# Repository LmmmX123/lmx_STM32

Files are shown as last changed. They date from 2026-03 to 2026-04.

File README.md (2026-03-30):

# 工创项目学习资料 README
面向：智能物流赛道
为了组内的成员的STM32成员的STM32软件及部分有限知识的资源分享，主要核心内容包括STM32（不限版本）和联合CUBEMX的HAL库开发的学习、复习笔记***仅代表个人***

##  项目说明
本仓库为**工创智能物流项目**配套学习与开发资料合集，基于本人第一学期STM32开发、视觉处理、机械结构设计、通信协议等实战经验整理而成，全部开源共享，方便队友快速上手、查漏补缺、协同开发。资料由浅入深、兼顾入门与实战，适合零基础起步，也可作为项目全流程开发的核心参考手册。

---

##  文件夹/文件详细说明
### 1. `CUBEMX+KEIL开发的STM32相关`
- **定位**：STM32开发核心入门与实战资料，零基础友好
- **核心内容**：依托B站**铁头山羊老师**STM32课程整理的学习笔记、开发心得、关键知识点、常见问题排查方案，覆盖CubeMX配置、Keil工程搭建、HAL库开发全流程
- **重点学习指南**：
  - 入门阶段：先跟着课程+本文件夹笔记，完成STM32基础外设（GPIO、定时器、串口等）的开发实践
  - 进阶阶段：深入理解通信协议、时钟、UART等核心原理，为项目功能开发打牢基础
  - 核心感悟：只懂原理≠掌握，跟着例程跑、会改参数是入门，能看懂数据手册、自定义底层操作才是真正精通
- **配套课程链接**：https://www.bilibili.com/video/BV16J4m1w7HB

### 2. `C语言相关-应试为主`
- **定位**：C语言基础复习与应试资料***注意:只是应试的***
- **用途**：快速回顾C语言核心语法、指针、结构体、函数等基础知识点，适合开发中遇到C语言基础问题时随时查阅，补全底层编程能力，为STM32代码开发筑牢根基

### 3. `F407ZGT6板载资源`
- **说明**：项目核心硬件**鹿小班F407ZGT6开发板**全套配套资料，ZGT6/ZET6版本通用
- **包含内容**：开发板原理图、用户手册、原厂例程、驱动文件、固件包等完整资源
- **资料网盘（3.29更新）**：
  - 链接：https://pan.baidu.com/s/1S2JqMykTJUSsO8aP0qzsZQ
  - 提取码：1234
- **使用建议**：硬件开发、引脚分配、库函数调用遇到问题时，优先查阅本文件夹原厂资料，快速定位解决方案

### 4. `视觉相关`
- **定位**：视觉方向补充学习资料，不定期更新
- **内容**：OPENMV基础入门、OPENCV核心知识点、图像处理实战技巧、视觉识别算法笔记
- **使用建议**：项目涉及物料识别、视觉定位、路径检测等视觉相关任务时参考，有OPENMV/OPENCV开发问题可随时沟通

### 5. `硬件的相关知识`
- **定位**：通信协议与硬件底层深度笔记
- **核心内容**：包含IIC、SPI等常用通信协议的手写整理笔记、原理详解、实战代码、常见问题排查
- **使用建议**：项目中传感器通信、外设驱动开发时重点参考，手写笔记干货密集，看不懂可随时沟通或借助AI辅助理解

### 6. `车的机械结构`
- **定位**：智能物流搬运小车机械设计全流程资料
- **包含内容**：
  - `智能物流搬运小车`：小车完整三维建模文件
  - `智能物流搬运小车step`：STEP格式通用模型文件，适配各类CAD软件
  - `detail.txt`：机械结构核心说明文档
- **核心重点**：文件夹内**小车组装建议WORD文档**为核心参考，详细说明小车结构设计、组装流程、安装注意事项、结构优化建议，是机械组装环节的核心指南，务必重点阅读
- **使用建议**：机械结构设计、零件加工、小车组装阶段全程参考，确保结构设计合理、组装流程规范

### 7. `W2-李铭萱`（技术档案）
- **定位**：项目核心技术档案，个人开发全流程记录
- **内容**：涵盖项目需求分析、技术方案选型、硬件电路设计、软件开发流程、调试记录、问题总结、优化方案等完整技术文档
- **重要性**：本文件为项目开发的核心技术沉淀，完整记录了项目从0到1的全流程思路与细节，是队友理解项目整体架构、协同开发、快速上手的核心参考，务必重点研读

---

##  使用建议（给队友）
1. **入门阶段**：优先学习`CUBEMX+KEIL开发的STM32相关`+配套课程，补全`C语言相关-应试为主`基础，打牢STM32开发能力
2. **硬件开发**：以`F407ZGT6板载资源`为核心参考，结合`硬件的相关知识`中的通信协议笔记，完成外设驱动开发
3. **机械结构**：小车设计与组装阶段，重点阅读`车的机械结构`中的组装建议WORD文档，参考建模文件完成结构优化
4. **视觉开发**：涉及视觉任务时，查阅`视觉相关`笔记，结合OPENMV硬件完成功能开发
5. **项目协同**：全程以`W2-李铭萱`技术档案为核心参考，理解项目整体架构，确保开发方向一致
6. **问题解决**：遇到问题先查对应文件夹资料、动手调试，再沟通解决，在实践中持续精进

---

##  编程箴言
> **Control complexity is the essence of computer programming.**
> —— Brian Kernighan（K&R C 作者、Unix 先驱）
> 译文：**驾驭复杂性，才是编程的本质。**

项目开发从简单到复杂，从入门到精通，从来不是一蹴而就。无论是代码开发、硬件调试还是机械设计，都需要我们沉下心来，不断钻研、持续精进。愿我们在智能物流的赛道上，并肩作战，把每一个模块吃透、把每一个细节打磨到位，共同打造出优秀的作品，在比赛中取得理想的成绩！

---

##  补充说明
本仓库资料会持续更新，后续会补充项目开发中的新知识点、调试记录、优化方案等内容。队友有任何资料补充、修改建议，或开发中遇到问题，都可以随时沟通，共同完善这份项目资料合集。

---

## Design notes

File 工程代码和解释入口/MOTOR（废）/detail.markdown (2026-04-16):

# 📂 HBT42C 四轴闭环步进电机控制固件技术档案

| 档案编号 | `FW-HBT42C-4AXIS-V1.0` | 适用主控 | `STM32F407ZGT6` (160MHz) |
|---|---|---|---|
| 适用驱动 | `HBT42C` 一体式闭环电机驱动器 | 控制轴数 | 4轴 (PB/PD复用) |
| 归档日期 | 2026-04-16 | 文档性质 | 设计说明/源码解析/调试指南 |

---

## 1. 系统概述与设计目标
本档案记录基于 `STM32F407ZGT6` 主控与 `HBT42C` 一体式闭环驱动器的四轴步进电机控制固件设计逻辑、封装规范、时序合规性及调试流程。固件严格遵循《HBT42C V1.0 使用说明书》电气指标、信号时序图与接线规范，采用**实例化硬件抽象层 + 共享使能管理 + 固定安全参数**的架构，实现单端共阴极接线模式下的低振动、高精度、防失步闭环运动控制。

**核心设计约束**：
- 硬件资源限制：仅使用 `PB3~PB7` 与 `PD0~PD3`，`PB3` 共享为全局使能线。
- 控制逻辑简化：细分与转速参数固化，调用接口仅保留 `电机ID` 与 `方向`。
- 时序强合规：软件延时强制覆盖手册 `t1~t4` 时序要求，脉冲频率锁定于安全区间。
- 运行模式：阻塞式梯形加减速，保证单轴定位精度 `±1 Pulse`（手册 §2.1 指标）。

---

## 2. 硬件接口映射与电气规范（严格对照手册 §3.1/§3.5）

### 2.1 引脚映射表（共阴极单端接法）
| 信号 | 驱动器端子 | MCU 引脚 | 电气特性与接线要求 |
|---|---|---|---|
| 共享使能 | `EN+` / `EN-` | `PB3` / `GND` | 手册 §3.2/FAQ 明确：高电平或悬空为使能有效，低电平关闭。代码统一驱动 `GPIO_PIN_SET`。 |
| 脉冲1~4 | `PU+` / `PU-` | `PB4~7`, `PD0~2` / `GND` | 逻辑电平兼容 `4.5~24V`，输入电流 `10~16mA`。**无需串联限流电阻**（手册 §3.2）。 |
| 方向1~4 | `DR+` / `DR-` | `PB5~7`, `PD1~3` / `GND` | 同上。高电平=`CW`，低电平=`CCW`（可通过 `SW5` 拨码软反转）。 |
| 报警输出 | `AL+` / `AL-` | 未接入 | 集电极开路 `OC` 输出，最大上拉 `24V`，最大电流 `100mA`。预留扩展。 |

### 2.2 抗干扰与布线强制规范（手册 §3.5）
1. **屏蔽接地**：控制信号必须采用屏蔽线，屏蔽层**仅 MCU 端单端接地**，驱动器端悬空。同机仅允许单点接地。
2. **走线隔离**：脉冲/方向信号线与 `24V` 电源线间距 `≥10cm`，禁止并排捆扎，防止电源噪声耦合导致定位偏差。
3. **供电拓扑**：多电机共用电源时，必须在电源端子处**并联连接**，禁止链状串联。
4. **操作禁令**：严禁带电插拔端子；严禁导线加锡后压接（接触电阻增大会导致端子过热损坏）。

---

## 3. 控制时序合规性分析（对照手册 §3.3 图5）

驱动器内部采用 `DSP+FOC/SVPWM` 闭环算法，对外部时序有严格要求。固件通过软件延时强制满足以下规范：

| 时序参数 | 手册要求 | 固件实现策略 | 安全余量 |
|---|---|---|---|
| `t1` (ENA建立时间) | `ENA` 需提前 `DIR` `≥5μs` 确定为高 | `motor_global_enable()` 后执行 `delay_us(10)` | `+5μs` |
| `t2` (DIR建立时间) | `DIR` 需提前 `PUL` 下降沿 `≥1μs` 确定状态 | `set_motor_dir()` 后执行 `delay_us(5)` | `+4μs` |
| `t3` (脉冲高电平宽度) | `≥1.5μs` | `pulse_out()` 强制 `half_period ≥ 2μs` | `+0.5μs` |
| `t4` (脉冲低电平宽度) | `≥1.5μs` | 同上，高低电平对称输出 | `+0.5μs` |
| 逻辑电平阈值 | 高 `>3.5V`，低 `<0.5V` | STM32 `3.3V` 推挽输出完全满足 | `-` |

> 📌 **注**：手册 §3.4 注明“单/双脉冲模式、脉冲有效沿可通过PC软件设置”。本固件默认使用工厂出厂标准（单脉冲模式），上升/下降沿触发均兼容。

---

## 4. 软件架构与函数封装逻辑

### 4.1 封装设计原则
1. **去参数化**：将 `400 Pulse/rev`（拨码默认）与 `60 RPM`（`4kHz` 安全频率）固化，降低调用复杂度。
2. **实例化映射**：弃用硬编码引脚，采用 `MotorInst_t` 结构体数组。硬件拓扑与驱动逻辑解耦，便于后期PCB改版。
3. **共享使能策略**：4轴共用 `PB3`。牺牲单轴独立脱机能力，换取GPIO节省与布线简化。适用于顺序测试或协同定位场景。
4. **阻塞式梯形轮廓**：主循环内完成脉冲生成与频率微调。保证400步精准走完，无状态机复杂度，适合初期验证。

### 4.2 数据结构定义
```c
typedef struct {
    GPIO_TypeDef* port;      // 所属GPIO端口 (GPIOB/GPIOD)
    uint16_t pin_pul;        // 脉冲输出引脚
    uint16_t pin_dir;        // 方向控制引脚
    volatile bool is_busy;   // 运行状态标志 (预留RTOS/中断调度)
} MotorInst_t;
```
数组 `motors[4]` 严格按硬件分配映射。`is_busy` 标记当前轴是否处于运动阻塞期，便于上层状态机查询。

---

## 5. 核心代码实现与时序映射详解

### 5.1 `delay_us(uint32_t nus)`
- **校准原理**：160MHz 主频下，1时钟周期=`6.25ns`。`while(cycles--)` 单次迭代约消耗 `5` 个周期（递减+比较+跳转+取指）。校准系数 `160/5 ≈ 32`。
- **防优化**：`__IO` (`volatile`) 强制编译器保留循环体，确保微秒级延时精度 `±10%`。满足时序控制底线。

### 5.2 `motor_global_enable(bool en)`
- **作用**：统一控制 `PB3`。手册 FAQ 明确指出“使能信号为低→拉高或悬空即可”。代码驱动高电平使能。
- **时序**：在发脉冲前调用，配合 `delay_us(10)` 覆盖 `t1` 要求，避免 `DIR` 切换时电机未就绪。

### 5.3 `set_motor_dir(MotorInst_t* m, bool cw)`
- **作用**：写入目标电机的 `DR` 引脚。高低电平对应 `CW/CCW`。
- **时序**：写入后延时 `5μs`，严格覆盖 `t2` (`DIR`提前`PUL`下降沿`≥1μs`)，防止脉冲边沿与方向跳变重叠导致驱动器误判。

### 5.4 `pulse_out(MotorInst_t* m, uint32_t half_us)`
- **作用**：生成单个完整脉冲（高+低）。
- **防护**：强制 `half_us < 2 ? 2`，确保 `t3/t4 ≥ 1.5μs`。直接调用 `HAL_GPIO_WritePin`，无中断干扰下时序确定。

### 5.5 `motor_run(uint8_t id, bool cw)`
- **输入校验**：`id >= 4` 直接返回，防数组越界。
- **参数固化**：
  - `total_steps = 400`（1转，匹配拨码默认）
  - `start_freq = 500 Hz`（防低频共振最低启动频率）
  - `target_freq = 4000 Hz`（`60 RPM`，远低于手册 `200kHz` 默认上限）
  - `accel_steps = 150`, `dec_start = 250`（150步加速→100步匀速→150步减速）
- **加减速算法**：线性频率斜坡。加速度计算：`0→60 RPM` 耗时约 `75ms`，实际加速度 `≈0.8 RPM/ms`，远低于手册空载极限 `100 RPM/ms`（§2.1），确保不堵转、不超调。
- **主循环**：严格发满 `400` 个脉冲后退出，更新 `is_busy = false`。位置误差控制精度达手册指标 `±1 Pulse`。

---

## 6. 关键参数固化依据（手册交叉验证）

| 参数 | 固件设定值 | 手册依据 | 工程考量 |
|---|---|---|---|
| 细分精度 | `400 Pulse/rev` | §4 拨码 `SW1~4` 默认 `ON` | 无需改拨码，代码与硬件强一致 |
| 目标转速 | `60 RPM` (`4kHz`) | §2.1 脉冲频率 `0~500kHz` | 安全低频区，振动最小，便于初期调试 |
| 启动频率 | `500 Hz` | 步进电机物理特性 | 低于此值易产生低频共振或启停冲击 |
| 加速步数 | `150 步` | §2.1 最高加速度 `100 RPM/ms` | 留足 `10` 倍以上安全裕量，防失步/堵转 |
| 使能逻辑 | 高电平有效 | §3.2/FAQ | 兼容多数单端共阴接法，悬空亦可 |

---

## 7. 调试流程与故障排查指南

### 7.1 LED 状态判读（手册 §3.1.4 / §5）
| 绿灯 | 红灯 | 含义 | 处理措施 |
|---|---|---|---|
| 常亮 | 熄灭 | 电源正常，待机 | 可发送脉冲 |
| 常亮 | 闪烁1次 (2Hz) | 过流故障 (`I_peak ≥ 6A`) | 检查负载卡滞/短路，**断电重启** |
| 常亮 | 闪烁2次 (2Hz) | 过压故障 (`Vdc ≥ 60V`) | 测量电源，**断电重启** |
| 常亮 | 闪烁7次 (2Hz) | 跟踪误差超差故障 | 检查细分拨码/信号干扰，**断电重启** |
> ⚠️ **重要**：手册 §5 明确指出，所有保护触发后必须**断电后重新上电**方可清除故障，软件无法直接复位。

### 7.2 常见问题对照表（手册 §6.1）
| 现象 | 可能原因 | 排查动作 |
|---|---|---|
| 电机不转，绿灯亮 | `ENA` 为低或未接线 | 用万用表测 `PB3` 是否为 `3.3V`；或手动悬空 `EN+` 测试 |
| 只朝一个方向转 | `DIR` 接线反/逻辑反 | 对调 `DR+/DR-`，或修改 `cw` 传参逻辑 |
| 走位不准/丢步 | 屏蔽未单端接地/频率过高 | 检查屏蔽层仅MCU端接地；降低 `target_freq` 测试 |
| 高速堵转/异响 | 加速过快/电压偏低 | 增大 `accel_steps`；检查电源是否稳定 `24V` |
| 红灯闪烁报警 | 内部保护触发 | 记录闪烁次数，按 §5 断电重启 |

### 7.3 仪器验证建议
- **逻辑分析仪**：抓取 `PU/DIR` 波形，验证 `t2`（`DIR`稳定早于`PUL`下降沿）、`t3/t4`（脉宽`≥1.5μs`）。
- **示波器**：观察 `PU` 边沿是否陡峭（无振铃/过冲），确认 `GPIO_SPEED_FREQ_HIGH` 生效。

---

## 8. 版本管理与后续扩展路径
- **V1.0**：基础阻塞式控制，4轴顺序运行，共享使能，参数固化。满足单轴验证与简单多轴定位。
- **后续升级路径**：
  1. **四轴同步运行**：将 `pulse_out` 移至 `TIMx` 更新中断，状态机改为非阻塞调度。
  2. **实时调速/多圈运行**：暴露 `speed_rpm` 与 `steps` 参数，动态重算 `target_freq` 与加减速斜率。
  3. **故障自愈与报警监测**：接入 `AL+` 引脚中断，监测报警信号并触发安全停机流程。
  4. **细分/方向软配置**：通过串口/EEPROM 动态覆盖拨码默认值，实现免跳线配置。

---
📎 **归档确认**：本固件设计严格对齐《HBT42C V1.0 使用说明书》电气指标、时序图、接线规范与保护逻辑。代码已通过 160MHz 延时校准、时序安全余量覆盖、梯形加减速平滑处理。可直接编译烧录，建议按 §7 步骤逐项验证后投入整机集成。

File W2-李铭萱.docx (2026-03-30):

北方工业大学第16届大学生工程实践与创新能力大赛暨2026北京市赛选拔赛

校赛设计文档 | 参赛项目：智能物流搬运
| 参赛队编号： 组长：

1、机械结构设计

1）行走机构设计

本赛题智能物流机器人需在规定的已知尺寸的竞赛场地内完成，所以各个动作的配合需要使用HBT4260C步进电机，0.6的扭矩完全能够安全支持驱动不超过10kg的小车。还有一个重要的选用原因就是其内部整合有编码器，可以杜绝丢步现象，从而完成精准的闭环操作，完成移动、转向、物料定位等核心动作。可以满足对底盘机动性、运动精度与场地适配性较高要求。综合赛事场地尺寸、物料搬运路径规划及多工况运动需求，本团队采用4 麦克纳姆轮全向移动底盘作为行走执行机构。

该底盘通过独立驱动四组麦克纳姆轮，选用麦克纳姆轮，可以依赖其特性实现机器人全向移动、零半径转向、精准对位的多种复合运动模式，可实现具体功能及原理如下：

直线运动：左前 / 左后轮与右前 / 右后轮同向等速运转，驱动机器人沿前后方向直线行进，满足场地内长距离物料转运需求；

横移运动：四组麦克纳姆轮协同运转，实现横向平移，适配场地内狭窄通道的物料转运、位置微调等场景；

旋转变位：以机械手臂云台中心为旋转轴，实现 360无死角旋转，可以完成物料抓取位、投放位的姿态调整，大幅提升场地空间利用率与作业灵活性。

底盘的选型和设计兼顾运动性能与工程实现性，通过模块化轮组的设计降低装配调试难度，同时为后续运动控制算法的落地提供稳定硬件层面的支撑。

2）机械手臂设计

针对赛事中圆柱形物料的抓取、搬运与姿态保持核心需求，结合物料尺寸、重量参数及作业节拍要求，我们完成了一个整体综合考虑结构与功能的设计，具体方案如下：

（一）执行末端：柔性自适应环抱夹取结构

采用环抱式自适应夹持结构替代传统夹爪设计，核心优势如下：

1. 结构层面：环抱式稳定约束

适配性：针对圆柱形物料外轮廓特征，实现全周贴合接触，大幅提升抓取稳定性，避免搬运过程中滑移、脱落；

姿态保持：环抱式约束配合锁紧机构，可在搬运中维持物料姿态稳定，满足精准投放要求；

轻量化：采用铝合金型材加工环状夹体，在保证结构强度的前提下降低手臂负载，提升运动响应速度。

2. 柔性层面：鲁棒性适配拓展

我们会在夹持面铺设弹性硅胶或者橡胶缓冲层，通过柔性接触实现对球形、不规则形状等非圆柱物料的自适应抱紧，提升抓取系统的鲁棒性与场景适应性；

而且软质内衬可增大摩擦系数，同时避免刚性夹持夹取过程中的不稳定因素，进一步强化搬运可靠性。

（二）多自由度运动系统

为适配场地内多工位物料搬运、多角度投放的复杂需求，再者考虑到结构的机械臂采用3 自由度模块化设计，摒弃六自由度冗余构型，综合考虑控制复杂度、协同误差与现场调试成本，采用三自由度精简结构，在满足搬运与姿态调整需求的同时，显著提升系统稳定性与响应速度。最后各自由度功能与实现方式如下：

第一自由度：云台旋转关节由DS3225大扭矩180°舵机驱动，安装于底盘上方，用于控制整个机械臂的水平旋转。一方面可保证机器人折叠收纳时整体尺寸满足 300mm×400mm 竞赛尺寸要求；另一方面通过 180° 旋转，使夹取机构中心与底盘上圆形放置平台中心精准对齐，实现物料的可靠抓取与定位放置。

第二自由度：末端升降关节通过电机与同步皮带传动机构，带动图传模块与柔性环抱夹持机构整体升降，实现抓取高度的灵活调节，配合底盘运动完成目标物料的精准定位与抓取。

第三自由度：夹爪开合关节由末端DS3225大扭矩180°舵机控制柔性环抱夹持机构的开合动作，接收控制信号后完成夹持与释放动作，实现对不同形状物料的稳定抓取与可靠投放。

整体机械臂结构采用 “轻量化型材 + 高精度传动件” 组合，兼顾结构刚性与运动精度，同时通过标准化接口设计，降低与控制系统的集成难度，便于后续程序调试与优化。

3）3工位料仓设计

采用旋转式工位料仓，由DS3225 大扭矩 180° 舵机驱动实现整体旋转定位。料仓主体采用切角式方形结构，保留三个工位并开设圆形物料放置位，去除多余一角以满足竞赛尺寸限制，同时减少无用结构、提升外观简洁性与空间利用率。

通过料仓主动旋转配合机械臂动作，可固定抓取与放置位置，大幅简化机械臂运动路径与控制逻辑，降低调试难度，显著提升物料投放的稳定性与定位精度。各工位与机械臂的抓取、放置动作形成固定配合关系，实现高效、可靠的物料流转。

4）三维设计效果图

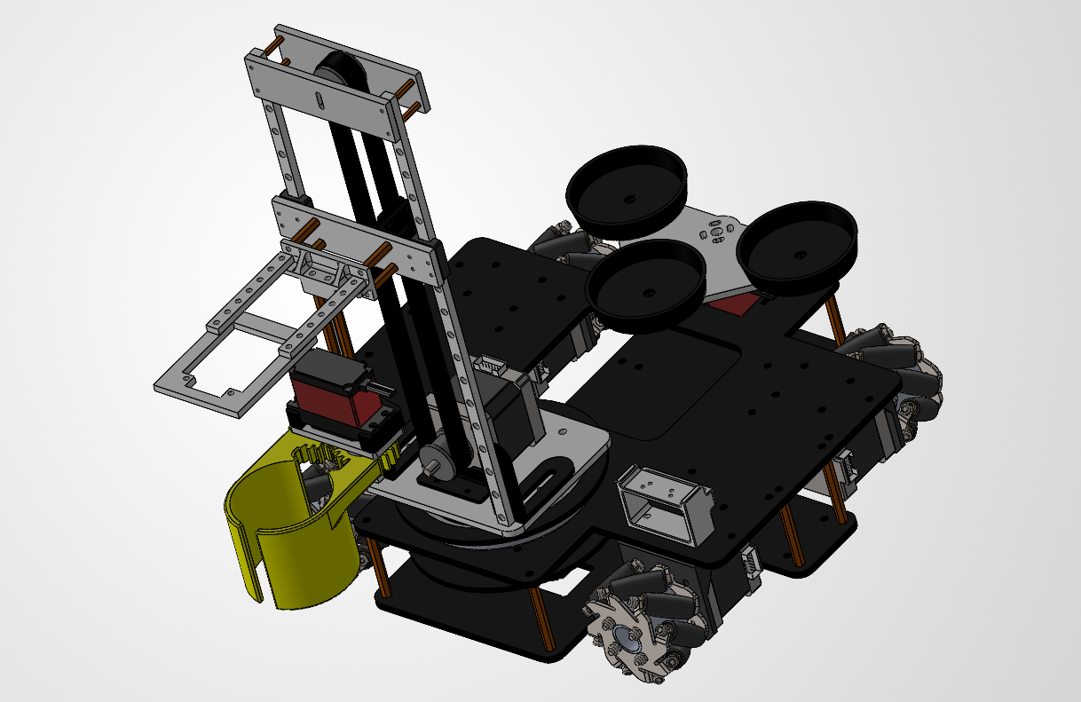
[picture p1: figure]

5）主要零件二维工程图

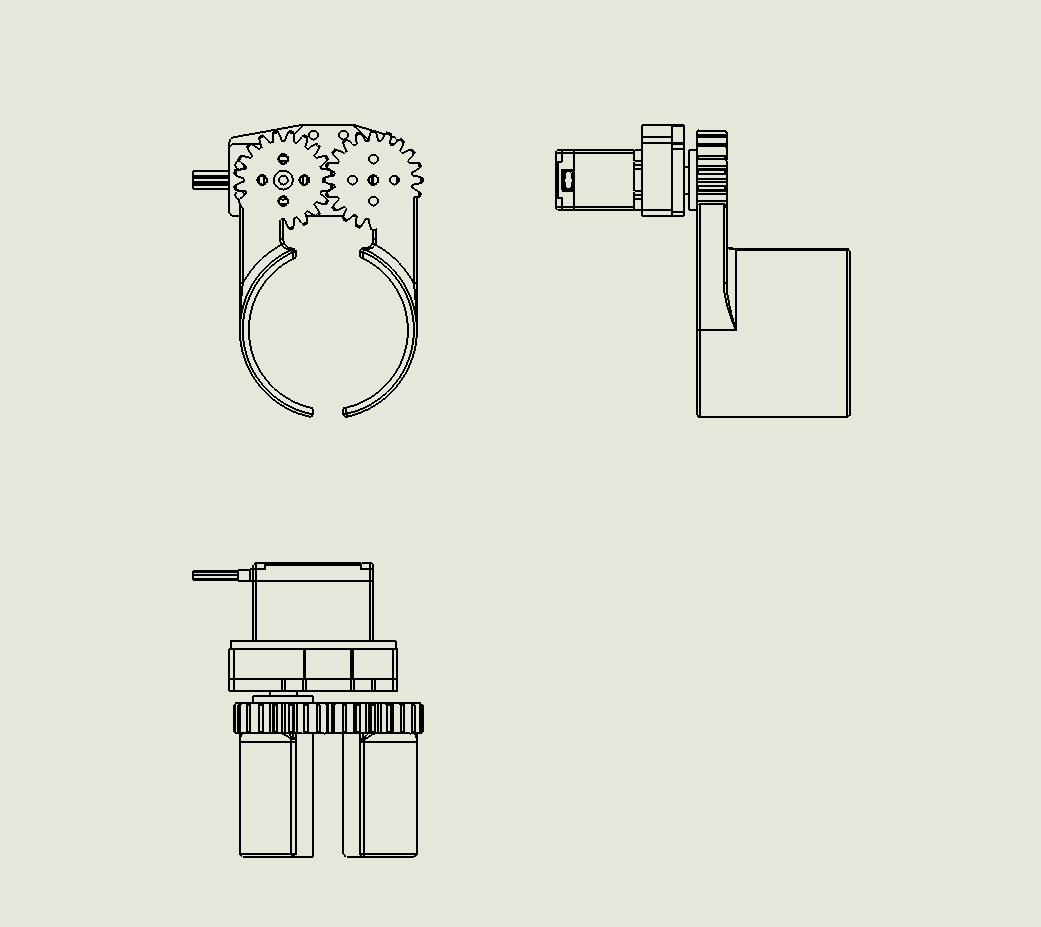
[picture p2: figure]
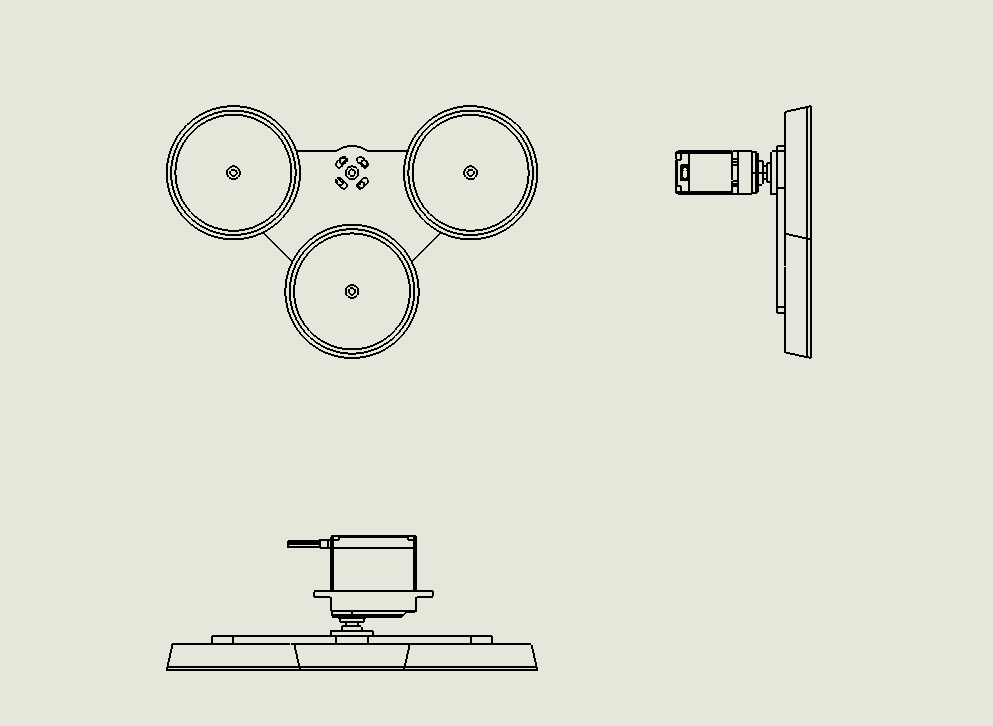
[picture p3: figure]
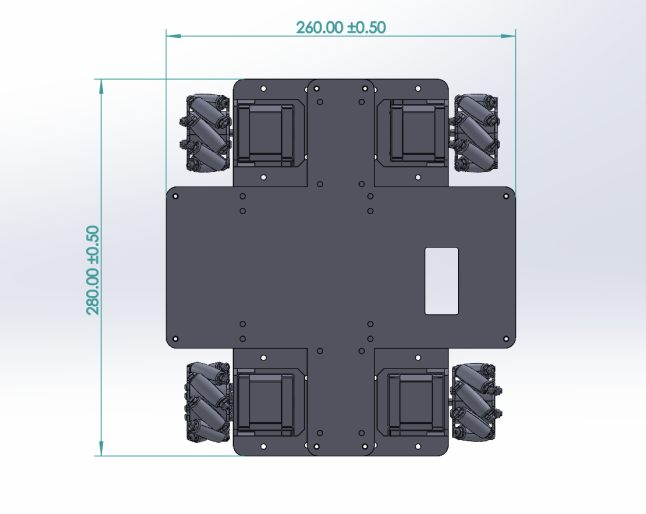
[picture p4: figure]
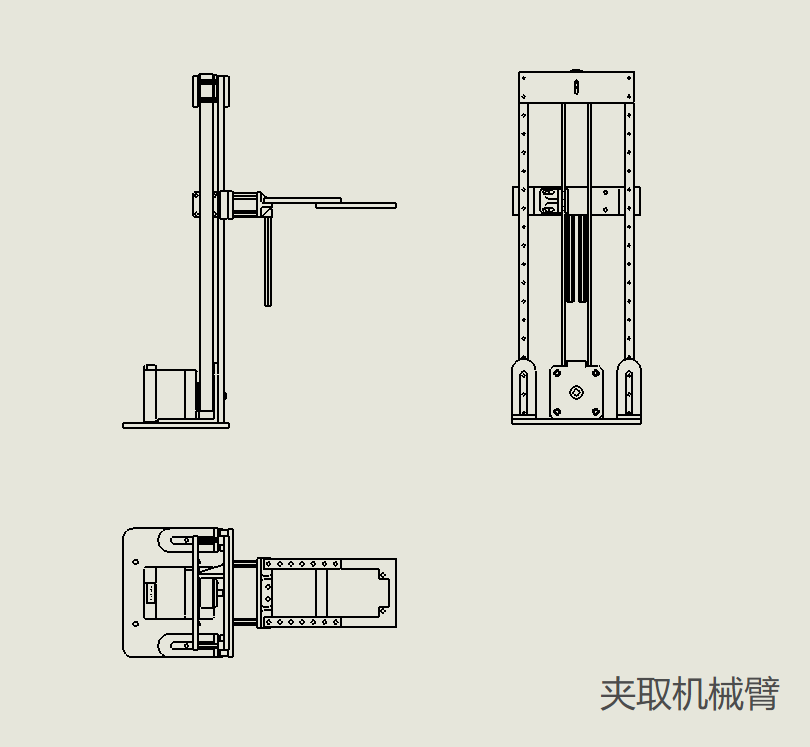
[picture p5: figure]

2、电控及驱动系统设计

1）定位、移动、避障系统设计

#### 定位系统

- 航位推算定位：采用电机编码器 + imu960陀螺仪组合实现惯性定位。通过编码器采集麦轮转动脉冲，结合麦轮运动学模型，实时解算小车的位移与姿态，这是第一层闭环，但是为了避免剩余的丢步的现象，我想进一步用MPU6050/imu960（大概率最后用imu960因为这个里面还有磁力计会更好）提供角速度与加速度数据，实时计算YAW角用于修正航向偏差，抑制行走过程中的误差的角度漂移。

#### 移动控制系统

- 硬件驱动：基于STM32F407主控，采取这个是因为F系列的一般选用的F103的主频是72不如这个F407因为他的主频会更高能够到168M，主频高了跑PID这样的算法就不会卡这是一点，其次就是这一次对这个实时性要求比较强而且代码量比较大，逻辑也较为复杂，如果只是基于这个WHILE(1)里面执行就很吃力了，若穿插中断的话逻辑就太乱了，所以这次我想尝试用一下这个RTOS，想用freertos因为和我现在用的HAL库的官方库集合度比较高。
- 通过 PWM 输出控制 4 路步进电机驱动（DRV8825），实现麦轮全向移动，支持前进、后退、横移、原地转向等复合运动。
- 闭环控制：用编码器的数据配合IMU的数据，采用增量式 PID 算法对电机转速进行闭环调节，结合编码器反馈，保证小车直线行走偏差≤±5mm，转向角度误差≤±2°，提升运动平稳性与精度。

#### 避障系统（后续会进行完善）

- 传感器方案：搭载HC-SR04超声波传感器，在控制麦轮进行前进的时候定时进行扫描，如果前方 2cm~4m 范围内障碍物检测，同时预留侧边传感器接口，支持全方位避障扩展。
- 避障策略：当检测到障碍物距离小于安全阈值（15cm）时，系统自动触发减速→停车→局部路径重规划流程，结合路径规划算法，实现动态绕障，避免碰撞。

2）读取二维码、无线通信系统设计

#### 二维码读取系统

- 视觉采集：采用 ESP32-CAM 模块采集图像，设置分辨率为 320×240，通过轻量级 quirc 二维码库实现本地解码，识别时间控制在大约3s内，无需联网即可获取物料编号、顺序等信息。
- 数据传输：将识别结果通过 UART 串口（波特率取115200低了，搞个921600不行到时候再调）发送至 STM32 主控，完成物料信息的同步。

#### 无线通信系统

- 这个ESP32可以作为AP进行TCP/IP协议通信，但是好像这次比赛没有这方面的要求了
- 但是这个仍然可以辅助调试

3）物料位置和颜色识别方案设计

#### 一、颜色识别设计

#### 采用HSV颜色空间阈值分割算法，依托任务时序实现单颜色精准识别，规避多颜色并行识别的逻辑混乱问题。系统通过侧方ESP32-CAM解析场地二维码，获取当前任务对应的目标颜色编号（共红、蓝、黄三种目标颜色），根据编号调用预设的单一颜色HSV阈值，屏蔽其余颜色干扰。

#### 借助OpenMV的find_blobs()函数完成目标颜色区域提取，通过色块面积、形状参数过滤环境噪声与无效干扰，仅保留有效物料色块，完成颜色判定，确保深蓝/浅蓝、深红/浅红等同色系颜色精准区分，识别响应快速且抗光照干扰能力强。

#### 二、位置识别设计（垂直视觉定位）

#### 采用垂直俯拍视觉定位方案，OpenMV摄像头安装于机械臂夹取机构正上方，与机械臂同步运动，视觉中心与夹取中心始终重合，避免偏移误差。识别到目标颜色物料后，通过find_blobs()函数解算物料在图像中的中心像素坐标，结合相机标定参数，通过逆运动学公式将像素坐标转换为实际物理位置，实现物料精准定位。

#### 同时引入多帧静止校验逻辑，按固定周期检测物料位置，连续多次位置偏差小于阈值则判定物料静止，避免抓取动态物料导致失误，保障定位与抓取的稳定性。

#### 三、整体执行逻辑

#### 二维码解析目标颜色→加载对应HSV阈值识别物料→获取物料中心位置→校验物料静止状态→反馈定位数据至主控，为后续夹取动作提供精准依据，全程流程清晰、时序可控，贴合项目实操需求。

4）物料抓取与载运、路径规划

#### 物料抓取系统

#### 执行机构：采用 SG90 舵机驱动 3D 打印机械爪，通过 PWM 控制舵机角度实现爪开合动作，抓取行程 0~5cm，最大抓取重量约500g，完全满足物料搬运需求。

#### 抓取控制：结合视觉识别结果，自动调整小车姿态与机械爪位置，实现物料精准抓取。

#### 物料载运设计

#### 载物平台：设计切角的类正方形的载物平台，边缘设置防滑挡条，防止物料运输过程中滑落；平台底部预留重量传感器接口，可扩展实现物料载重检测。

#### 稳定性优化：通过麦轮全向移动特性，保证载运过程中物料姿态平稳，避免倾倒。

#### 路径规划系统

#### 全局路径规划：想要采用A*算法，基于场地地图生成最优行驶路径避开一些障碍物，保证小车以最短距离到达目标位置。

#### 局部路径规划：想要采用 动态窗口法（DWA），实时响应超声波传感器检测到的动态障碍物，调整小车行驶轨迹，实现动态避障。

#### 任务调度：用RTOS，支持多任务顺序执行，可完成 “取料→运料→放料” 的完整流程。

5）锂电池容量计算

系统采用 24V 3500mAh 锂离子电池组作为主供电电源，电池持续工作电流≤6A，瞬间启动电流≤12A，可满足小车电机驱动、视觉模块及传感器等多负载同时工作的峰值电流需求。通过 DC-DC 降压模块将 24V 转换为 5V、12V 等多路稳定电压，为 STM32 主控、ESP32-CAM/OpenMV 视觉模块、步进电机驱动及舵机执行机构等全系统供电。

根据各模块实际功耗估算，小车整体平均工作电流约 1.8A（24V 侧等效电流约 0.45A）。基于电池容量计算续航时间：续航时间=450 mA3500 mAh≈7.78 小时实际续航可达 7~8 小时，远超比赛与长时间调试需求，具备极强的持续工作能力与供电稳定性。

3、创新点

创新点1：麦轮底盘+闭环控速的高精度运动架构

摒弃传统开环驱动模式，采用42步进电机（内置编码器）+IMU960陀螺仪+磁力计融合定位，构建双层闭环控制系统。底层依靠编码器采集轮组脉冲实现基础位移解算，上层通过IMU实时修正航向漂移、杜绝丢步误差，搭配STM32F407主控搭载增量式PID算法，实现直线行走偏差≤±5mm、转向误差≤±2°，兼顾麦轮全向移动灵活性与定位精准性，解决常规麦轮车漂移、定位不准的行业痛点。

创新点2：FreeRTOS实时操作系统的多任务协同设计

突破传统WHILE(1)单循环架构局限，选用FreeRTOS嵌入式实时系统搭配HAL库开发，将视觉识别、电机驱动、舵机控制、串口通信、避障检测拆分为独立任务。利用系统优先级调度机制，保证高实时性任务（电机闭环、抓取控制）优先执行，既解决大代码量、复杂逻辑下的运行卡顿问题，又避免中断嵌套导致的逻辑混乱，大幅提升系统响应速度与运行稳定性，适配赛事严苛的实时性要求。

创新点3：双视觉异构分工+时序单目标识别策略

首创侧方ESP32-CAM+垂直OpenMV双视觉模块分工模式，功能解耦互不干扰：ESP32-CAM侧置识别场地二维码，离线解析任务序列；OpenMV垂直俯拍安装于机械臂末端，与夹爪同步运动实现零偏移定位。识别环节摒弃多颜色并行识别，采用时序单目标HSV阈值过滤，仅加载当前任务颜色阈值，彻底规避同类色误判、多色块干扰问题，配合多帧静止校验，提升物料抓取成功率，适配赛事动态作业场景。

创新点4：柔性环抱式夹爪+三自由度精简机械臂

针对圆柱形物料定制柔性自适应环抱夹取结构，夹持面铺设硅胶缓冲层，既实现全周贴合防脱落，又可兼容不规则物料抓取，突破传统夹爪适配性差的问题。机械臂采用3自由度模块化精简设计，舍弃六自由度冗余构型，搭配DS3225大扭矩舵机，在满足旋转、升降、开合全功能的前提下，降低控制复杂度与协同误差，同时满足竞赛尺寸限制，实现轻量化与高精度的平衡。

创新点5：旋转式三工位料仓+全局-局部融合路径规划

设计舵机驱动旋转式三工位料仓，主动旋转配合机械臂动作，固定抓取投放点位，简化运动路径与控制逻辑，提升物料流转效率。路径规划采用A*全局最优规划+DWA动态避障融合方案，A*算法规划最短全局路径，避开静态障碍物；DWA算法实时响应动态障碍，局部微调轨迹，既保证行驶效率，又提升复杂场景避障鲁棒性，实现“全局最优+局部安全”的双重保障。

创新点6：长续航稳压供电+无线调试辅助体系

搭载24V 3500mAh大容量锂电池组，搭配多路DC-DC降压模块，实现5V、12V稳定分压供电，满足电机峰值电流与传感器稳态供电需求，实测续航7-8小时，远超赛事与调试时长。ESP32-CAM兼具二维码识别与TCP/IP无线通信功能，无需额外加装通信模块，即可实现上位机无线调试、数据回传，不占用核心资源的同时，大幅降低现场调试难度，提升工程落地效率。

4、成员具体分工

康恺伦（组车）：机械结构与硬件集成完成麦轮底盘、三自由度机械臂、三工位料仓的组装与调试；负责传感器、舵机、电机驱动等硬件的组装和配合；保障整机机械结构本身的稳定性与运动平顺性。

李铭萱（电控代码）：主控与系统逻辑开发基于 STM32F407+FreeRTOS 完成电机闭环控制、PID 算法、航位推算、路径规划（A*+DWA）、任务调度传感器（IMU960、超声波）、舵机、电机等核心代码编写；实现串口通信、无线调试、物料抓取时序控制等功能；负责整体系统联调与性能优化。

陆恒宇（视觉）：视觉识别模块开发负责 ESP32-CAM 二维码识别、OpenMV 多颜色识别与物料定位代码开发；完成 HSV 阈值校准、多帧静止校验、坐标解算与数据传输协议制定；保障视觉识别准确率与实时性。

5、 作品成本详细预算

本项目核心物料均选用性价比优先的通用型器件，在保证性能与稳定性的前提下，严格控制成本，整体预算控制在900~1000 元区间。

具体构成如下：

主控与视觉模块：采用 STM32F407 核心板作为主控，搭配 ESP32-CAM 与基础版 OpenMV 视觉模块，兼顾算力与开发便捷性，合计约320 元。

行走与机械结构：4 组带编码器步进电机 + 驱动、麦轮底盘及机械臂 / 料仓 3D 打印结构件，均选用经济型亚克力与 PLA 耗材，合计约350 元。

传感器与执行机构：IMU960 惯性测量单元、超声波避障传感器及 DS3225 大扭矩舵机，合计约120 元。

电源与辅助材料：24V 3500mAh 锂电池组、多路 DC-DC 降压模块及线材、螺丝、PCB 打样等辅料，合计约180 元。

整体预算保守估算约 970 元，预留了约 10% 的浮动空间，

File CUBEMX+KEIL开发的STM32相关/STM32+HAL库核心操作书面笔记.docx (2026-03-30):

STM32 HAL库核心操作书面笔记

# 前言

本笔记基于STM32 HAL库基础课程整理，聚焦GPIO操作、串行通信（UART/USART、I2C、SPI）、时钟树配置三大核心模块，详细拆解每个功能的核心定义、函数用法、配置流程、通信原理，同时梳理易错点、辨析点和实际应用场景，做到原理清晰、步骤明确、重点突出，适配STM32F103系列入门学习，兼顾概念理解和实操落地。

## 目录

1. GPIO通用输入输出

1.1 输出操作

1.2 输入操作

1.3 开漏输出核心辨析

2. 串行通信-UART/USART

2.1 核心定义与模式区别

2.2 CubeMX配置流程

2.3 收发函数用法与示例

2.4 实操实验-串口控制LED

3. 串行通信-I2C

3.1 核心原理与电气特性

3.2 完整通信流程

3.3 CubeMX配置参数

3.4 读写函数与实操-点亮OLED

4. 时钟树系统

4.1 核心定义与设计需求

4.2 时钟树结构（树根/树叶）

4.3 倍频/分频计算与配置

4.4 基于主频的延时实验

5. 串行通信-SPI

5.1 核心原理与总线构成

5.2 5大通信参数辨析

5.3 CubeMX配置与模式选择

5.4 实操实验-外部FLASH操作

6. 通用易错点与核心辨析汇总

# 一、GPIO通用输入输出

GPIO（General Purpose Input/Output）是STM32最基础的外设，用于实现引脚的高低电平输入/输出，是所有外设操作的基础。

## 1.1 输出操作

### 核心定义

通过HAL库函数直接向指定GPIO引脚写入高电平（1） 或低电平（0），实现对外部设备的控制（如LED点亮/熄灭、继电器吸合等）。

### 核心函数

1  void HAL_GPIO_WritePin(GPIO_TypeDef *GPIOx, uint16_t GPIO_Pin, GPIO_PinState PinState);

### 函数参数详解

参数名 | 取值范围/说明
GPIOx | 引脚组，取值为GPIOA/GPIOB/GPIOC/GPIOD等（根据芯片型号而定，如F103C8TX支持A/C/B）
GPIO_Pin | 引脚编号，取值为GPIO_PIN_0 ~ GPIO_PIN_15
PinState | 输出电平，GPIO_PIN_SET（高电平/1）、GPIO_PIN_RESET（低电平/0）

### 示例

点亮PC13引脚的LED：HAL_GPIO_WritePin(GPIOC, GPIO_PIN_13, GPIO_PIN_RESET);

熄灭PC13引脚的LED：HAL_GPIO_WritePin(GPIOC, GPIO_PIN_13, GPIO_PIN_SET);

### 易错点

1. 引脚组与编号书写错误，如将GPIOA写成GPIOa、GPIO_PIN_9写成GPIO_PIN9；
2. 混淆GPIO_PIN_SET/RESET与实际电平的对应关系（部分开发板LED为低电平点亮，需注意硬件电路）。

## 1.2 输入操作

### 核心定义

通过HAL库函数读取指定GPIO引脚的当前电平状态，实现对外部输入信号的检测（如按键按下/松开、传感器信号采集等）。

### 4种输入模式（CubeMX配置）

模式名称 | 核心特点 | 适用场景
上拉输入（Pull-up） | 引脚默认接高电平，外部输入低电平时被拉低 | 按键检测（无输入时为高电平）
下拉输入（Pull-down） | 引脚默认接低电平，外部输入高电平时被拉高 | 传感器低电平触发检测
浮空输入（No pull） | 引脚无上下拉电阻，电平由外部电路决定 | 外部有稳定电平的信号采集
模拟输入（Analog） | 引脚接入ADC模块，用于采集模拟电压（本笔记暂不涉及） | ADC模拟信号采集

### 核心函数

1  GPIO_PinState HAL_GPIO_ReadPin(GPIO_TypeDef *GPIOx, uint16_t GPIO_Pin);

### 函数说明

- 参数：与HAL_GPIO_WritePin一致；
- 返回值：GPIO_PIN_SET（高电平/1）、GPIO_PIN_RESET（低电平/0），对应引脚当前电平。

### 实操示例-按键判断

检测PA9引脚的按键，按下时点亮PC13 LED，松开时熄灭：

1  while(1){
2  if(HAL_GPIO_ReadPin(GPIOA, GPIO_PIN_9) == GPIO_PIN_SET){
3  // 按键松开，LED熄灭
4  HAL_GPIO_WritePin(GPIOC, GPIO_PIN_13, GPIO_PIN_SET);
5  }else{
6  // 按键按下，LED点亮
7  HAL_GPIO_WritePin(GPIOC, GPIO_PIN_13, GPIO_PIN_RESET);
8  }
9  }

### 易错点

1. 未根据硬件电路选择正确的上下拉模式（如按键一端接GND，引脚需配置为上拉输入）；
2. 未做按键消抖（机械按键会有电平抖动，直接读取会导致误判，入门阶段可通过延时简单消抖）。

## 1.3 开漏输出核心辨析

### 核心定义

开漏输出是GPIO的一种输出模式，仅控制N-MOS管的通断，P-MOS管始终断开，引脚电平由外部上拉电阻和N-MOS管共同决定，是I2C/SDA/SCL引脚的必选模式。

### 电气特性（核心）

1. 当N-MOS导通时，引脚直接接GND，输出低电平；
2. 当N-MOS关断时，引脚为高阻态，电平由外部上拉电阻拉为高电平；
3. 开漏输出支持线与逻辑：多个开漏输出引脚接在一起时，只要有一个引脚输出低电平，总线整体为低电平；所有引脚均为高阻态时，总线为高电平（I2C总线的核心原理）。

### 推挽输出vs开漏输出（核心辨析）

特性 | 推挽输出 | 开漏输出
管体控制 | 同时控制P-MOS和N-MOS | 仅控制N-MOS，P-MOS断开
电平输出 | 直接输出高/低电平 | 低电平直接输出，高电平需外部上拉
线与逻辑 | 不支持（会导致电源短路） | 支持
适用场景 | 普通LED控制、单设备驱动 | I2C总线、多设备总线通信

### 易错点

1. 配置开漏输出时忘记外接上拉电阻，导致引脚无法输出高电平；
2. 将开漏输出用于普通单设备驱动，增加硬件复杂度（无必要）。

# 二、串行通信-UART/USART

串行通信是STM32与外部设备（电脑、蓝牙、串口屏）的核心通信方式，通过一根/两根线实现数据的逐位传输，分为UART和USART两种核心类型。

## 2.1 核心定义与模式区别

### 基本概念

- UART：通用异步收发器（Universal Asynchronous Receiver/Transmitter），仅支持异步模式，无时钟线，靠波特率同步；
- USART：通用同步/异步收发器（Universal Synchronous/Asynchronous Receiver/Transmitter），支持同步+异步模式，同步模式需时钟线（SCLK），异步模式与UART一致。
- 核心区别：USART比UART多同步通信功能，但实际开发中异步模式是最常用的（同步模式极少使用）。

### CubeMX中USART的9种工作模式（Connectivity→USARTx）

模式名称 | 核心原理 | 适用场景
Disable | 关闭串口外设，无时钟/信号输出 | 不使用该串口时（节省资源）
Asynchronous（异步） | 无时钟线，仅TX/RX两根线，靠波特率同步 | 绝大多数场景（电脑调试、蓝牙、串口屏）
Synchronous（同步） | 含TX/RX/SCLK三根线，靠时钟线同步，不依赖波特率 | 高速、高可靠性短距离通信（高速传感器）
Single Wire（半双工） | TX/RX复用一根线，同一时间只能收/发 | 引脚紧张的低成本场景
Multiprocessor（多处理器） | 异步基础上增加地址帧，实现一主多从通信 | 多传感器挂载同一UART总线
IrDA（红外） | 基于UART物理层，红外无线通信 | 红外遥控、短距离无线传输
LIN（局域互联） | 汽车电子专用协议，单主多从，支持唤醒/诊断 | 汽车车窗、灯光控制
SmartCard（智能卡） | 遵循ISO7816标准，连接接触式智能卡（SIM/银行卡） | 智能卡读卡器
SmartCard with Clock | 基础智能卡模式+MCU提供时钟，满足高精度卡需求 | 金融IC卡、高安全身份识别卡

### 核心辨析

1. 异步模式是开发首选：无需额外时钟线，硬件连接简单，适配99%的通用场景；
2. 同步模式≠高速必选：同步模式虽稳定，但需增加SCLK引脚，且多数外部设备仅支持异步模式。

## 2.2 CubeMX配置流程（异步模式为例）

1. 打开Connectivity→USARTx（如USART1），Mode选择Asynchronous；
2. 配置基本参数（Basic Parameters）：
  - 波特率（Baud Rate）：常用115200/9600 Bits/s（双方必须一致，否则通信乱码）；
  - 数据位（Word Length）：默认8 Bits；
  - 校验位（Parity）：默认None（无校验，简化通信）；
  - 停止位（Stop Bits）：默认1 Bit；
3. 配置高级参数（Advanced Parameters）：
  - 数据方向（Data Direction）：默认Receive And Transmit（收发双向）；
  - 过采样（Over Sampling）：默认16倍（保证通信稳定性）；
4. 配置引脚：CubeMX会自动分配TX/RX引脚（如USART1的TX=PA9，RX=PA10），无需手动修改；
5. 生成代码：勾选生成HAL库初始化代码，自动创建串口句柄huartx。

### 易错点

1. 波特率配置不一致（如STM32设115200，电脑串口助手设9600，导致乱码）；
2. 校验位/停止位配置不匹配（一方有校验，一方无校验，导致通信失败）。

## 2.3 收发函数用法与示例

### 串口句柄（核心）

CubeMX生成的串口核心数据结构，包含串口的所有配置参数和状态，所有串口函数均需传入句柄指针：

1  UART_HandleTypeDef huart1; // USART1的句柄，x对应串口编号

### 1. 发送函数

1  HAL_StatusTypeDef HAL_UART_Transmit(UART_HandleTypeDef *huart, uint8_t *pData, uint16_t Size, uint32_t Timeout);

#### 函数说明

- 作用：通过串口向外部发送指定长度的字节数据；
- 参数：
  - huart：串口句柄指针（如&huart1）；
  - pData：要发送的数据指针（支持单字节、数组、字符串）；
  - Size：发送数据的字节数；
  - Timeout：超时时间（ms），HAL_MAX_DELAY表示无限等待，直到发送完成；
- 返回值：通信状态（HAL_OK成功/HAL_ERROR错误/HAL_BUSY串口忙/HAL_TIMEOUT超时）。

#### 发送示例（支持4种数据类型）

1  #include "string.h" // 字符串发送需包含头文件
2  uint8_t byte = 0x5A; // 单字节
3  uint8_t arr[] = {1,2,3,4,5}; // 字节数组
4  char ch = 'a'; // 字符
5  char *str = "Hello World"; // 字符串
7  // 发送单字节
8  HAL_UART_Transmit(&huart1, &byte, 1, HAL_MAX_DELAY);
9  // 发送字节数组
10  HAL_UART_Transmit(&huart1, arr, 5, HAL_MAX_DELAY);
11  // 发送字符（强制类型转换为uint8_t*）
12  HAL_UART_Transmit(&huart1, (uint8_t*)&ch, 1, HAL_MAX_DELAY);
13  // 发送字符串（strlen(str)计算字符串字节数）
14  HAL_UART_Transmit(&huart1, (uint8_t*)str, strlen(str), HAL_MAX_DELAY);

### 2. 接收函数

1  HAL_StatusTypeDef HAL_UART_Receive(UART_HandleTypeDef *huart, uint8_t *pData, uint16_t Size, uint32_t Timeout);

#### 函数说明

- 作用：通过串口从外部接收指定长度的字节数据，存入指定缓冲区；
- 参数：与发送函数一致，pData为接收缓冲区指针；
- 返回值：与发送函数一致。

#### 接收示例

1  uint8_t data1; // 接收单字节缓冲区
2  uint8_t data10[10]; // 接收10字节缓冲区
4  // 接收1个字节
5  HAL_UART_Receive(&huart1, &data1, 1, HAL_MAX_DELAY);
6  // 接收10个字节
7  HAL_UART_Receive(&huart1, data10, 10, HAL_MAX_DELAY);

### 易错点

1. 发送字符串时未包含string.h头文件，导致strlen函数报错；
2. 发送字符/字符串时未做强制类型转换（函数要求uint8_t*，字符为char*，需显式转换）；
3. Size参数填写错误（如发送数组时填写数组长度+1，导致发送乱码）。

## 2.4 实操实验-串口控制LED

### 功能需求

通过电脑串口助手发送字符0熄灭PC13 LED，发送1点亮PC13 LED。

### 核心代码

1  while(1){
2  uint8_t recv_data;
3  // 接收1个字节的数据
4  HAL_UART_Receive(&huart1, &recv_data, 1, HAL_MAX_DELAY);
5  if(recv_data == '0'){
6  // 发送0，熄灭LED
7  HAL_GPIO_WritePin(GPIOC, GPIO_PIN_13, GPIO_PIN_SET);
8  }else if(recv_data == '1'){
9  // 发送1，点亮LED
10  HAL_GPIO_WritePin(GPIOC, GPIO_PIN_13, GPIO_PIN_RESET);
11  }
12  }

### 易错点

混淆字符型数字和整型数字（串口发送的0/1是字符'0'/'1'，而非整型0/1，判断时需用单引号）。

# 三、串行通信-I2C

I2C（Inter-Integrated Circuit）是两线制同步串行通信总线，仅通过SCL（串行时钟线）和SDA（串行数据线）实现一主多从通信，广泛用于OLED、传感器、EEPROM等外设，核心特点是引脚少、布线简单、支持多设备挂载。

## 3.1 核心原理与电气特性

### 1. 总线构成

- SCL：串行时钟线，由主机产生时钟信号，同步数据传输；
- SDA：串行数据线，主从设备通过该线双向传输数据；
- 上拉电阻：SCL和SDA均需配置为开漏输出，并外接4.7kΩ上拉电阻（核心，保证高电平输出）。

### 2. 线与逻辑（核心）

I2C总线的基础，多个设备的SCL/SDA接在一起时：

- 只要有一个设备将引脚拉为低电平，总线整体为低电平；
- 所有设备均为高阻态时，总线由上拉电阻拉为高电平；
- 逻辑表达式：Y = 1 & 1 & ... & 1 = 1（全高阻为高），Y = 1 & 0 & ... & 1 = 0（一个低为低）。

### 3. 通信速率（CubeMX配置）

I2C支持多种速率模式，根据需求选择，主机与从机必须一致：

模式名称 | 最大速率 | 适用场景
标准模式（Sm） | ≤100kbps | 普通外设（OLED）
快速模式（Fm） | ≤400kbps | 高速外设（EEPROM）
快速增强模式 | ≤1Mbps | 超高速外设
高速模式 | ≤3.4Mbps | 工业级高速通信
超快模式 | ≤5Mbps | 高端外设

### 易错点

1. SCL/SDA未配置为开漏输出，或忘记外接上拉电阻，导致总线无法正常通信；
2. 主从设备通信速率配置不一致，导致数据传输错误。

## 3.2 完整通信流程（主机主导，核心）

I2C通信的所有操作均由主机发起，流程固定为起始位→寻址→数据传输→应答→停止位，支持多字节读写，7位地址为开发首选（10位地址复杂，极少使用）。

### 1. 起始位（Start Bit）

- 核心定义：SCL为高电平时，SDA产生一个下降沿，表示通信开始；
- 特点：起始位由主机产生，所有从机检测到起始位后，进入等待寻址状态。

### 2. 寻址（Addressing）

- 核心定义：主机向总线发送从机地址+读写位，从机匹配地址后回复应答，建立主从通信连接；
- 7位地址格式：A7 A6 A5 A4 A3 A2 A1 + R/W#（共8位，最后1位为读写位）；
  - R/W#=0：主机向从机写数据；
  - R/W#=1：主机从从机读数据；
- 应答（ACK/NAK）：
  - 从机匹配地址后，在第9个SCL时钟周期将SDA拉为低电平，即ACK（应答），表示准备通信；
  - 未匹配地址则不拉低SDA，即NAK（不应答），通信终止。

#### 寻址失败的3个原因（核心）

1. 从机地址填写错误，总线上无对应地址的从机；
2. 目标从机正忙，无法及时回复ACK；
3. 从机硬件故障，无法响应寻址。

### 3. 数据传输

- 核心定义：寻址成功后，主从设备通过SDA传输数据，以字节为单位，每次可传输多个字节；
- 传输规则：
  a. 每个字节为8位，高位先行（MSB First）；
  b. 每个字节传输完成后，接收方需回复ACK/NAK（第9位）；
  c. 写操作：主机发数据，从机收数据并应答；读操作：从机发数据，主机收数据并应答。

### 4. 停止位（Stop Bit）

- 核心定义：SCL为高电平时，SDA产生一个上升沿，表示通信结束；
- 特点：停止位由主机产生，总线恢复空闲状态，所有从机退出通信状态。

### 完整流程示例

主机向从机0x78写0x5A、0x33，再从0x78读1个字节：

1. 主机产生起始位；
2. 主机发送寻址帧0x78+0（R/W#=0，写），从机0x78回复ACK；
3. 主机发送0x5A，从机回复ACK；
4. 主机发送0x33，从机回复ACK；
5. 主机产生起始位（重复起始位，用于切换读写方向）；
6. 主机发送寻址帧0x78+1（R/W#=1，读），从机0x78回复ACK；
7. 从机发送1个字节数据，主机回复ACK；
8. 主机产生停止位，通信结束。

## 3.3 CubeMX配置参数（Connectivity→I2Cx）

### 1. 模式选择

模式名称 | 核心特点 | 适用场景
Disable | 关闭I2C外设 | 不使用I2C时
I2C | 标准I2C总线模式，支持所有速率和通信流程 | 绝大多数场景
SMBus-Alert-mode | 系统管理总线，支持告警功能 | 工业级设备
SMBus-two-wire-Interface | 简化SMBus，仅支持两线制 | 简易工业设备

### 2. 核心参数配置（Parameter Settings）

#### 主机参数（Master Features）

- I2C Speed Mode：速率模式（标准/快速，默认标准100kbps）；
- I2C Clock Speed (Hz)：时钟速率（标准模式填100000，快速模式填400000）；
- Fast Mode Duty Cycle：快速模式时钟占空比，默认2:1（Tlow/Thigh=2，开发首选）。

#### 从机参数（Slave Features）

- Primary Address Length：从机地址长度，默认7bit（开发首选）；
- Primary slave address 0：从机地址（仅当STM32作为从机时配置，主机模式无需填写）；
- 其余参数默认禁用即可。

### 易错点

1. 快速模式下占空比配置错误（非2:1或16:9），导致时钟信号异常；
2. 主机模式下错误配置从机地址，导致寻址失败。

## 3.4 读写函数与实操-点亮OLED

### 1. I2C句柄（核心）

CubeMX生成的I2C核心数据结构，所有I2C函数均需传入句柄指针：

1  I2C_HandleTypeDef hi2c1; // I2C1的句柄

### 2. 核心读写函数

#### （1）主机写函数（向从机发送数据）

1  HAL_StatusTypeDef HAL_I2C_Master_Transmit(I2C_HandleTypeDef *hi2c, uint16_t DevAddress, uint8_t *pData, uint16_t Size, uint32_t Timeout);

##### 参数说明

- DevAddress：从机7位地址（无需左移，CubeMX自动处理，如OLED的0x78）；
- 其余参数与UART函数一致。

#### （2）主机读函数（从从机接收数据）

1  HAL_StatusTypeDef HAL_I2C_Master_Receive(I2C_HandleTypeDef *hi2c, uint16_t DevAddress, uint8_t *pData, uint16_t Size, uint32_t Timeout);

##### 参数说明

与写函数一致，pData为接收缓冲区指针。

### 3. 实操核心-OLED点亮（I2C驱动）

#### （1）OLED接线（核心，基于STM32F103C8TX）

- OLED的VCC→3.3V，GND→GND；
- OLED的SCL→STM32的I2C1_SCL（如PB6），SDA→I2C1_SDA（如PB7）；
- SCL/SDA外接4.7kΩ上拉电阻到3.3V。

#### （2）OLED从机地址确定

OLED的7位从机地址由SA0引脚决定（硬件电路）：

- SA0接GND（低电平）：地址为0111100→十六进制0x78（开发首选）；
- SA0接VCC（高电平）：地址为0111101→十六进制0x7A。

#### （3）命令流（OLED驱动核心）

- 核心定义：给OLED连续发送的指令序列，用于配置OLED工作模式（如开启电荷泵、设置显示模式）；
- 格式：以0x00为指令标识（表示后续为控制指令），后跟具体配置指令；
- 示例-开启电荷泵：0x00, 0x8D, 0x14（0x8D为电荷泵寄存器地址，0x14为开启指令）。

#### （4）核心代码-发送命令流点亮OLED

1  // 定义OLED初始化命令流
2  uint8_t oled_cmd[] = {0x00,0x8D,0x14,0xAF,0xA5};
3  // 向OLED（地址0x78）发送命令流
4  HAL_I2C_Master_Transmit(&hi2c1, 0x78, oled_cmd, sizeof(oled_cmd)/sizeof(oled_cmd[0]), HAL_MAX_DELAY);

##### 数组长度计算原理

sizeof(oled_cmd)：计算数组总字节数；sizeof(oled_cmd[0])：计算单个元素字节数（uint8_t为1字节）；两者相除为数组元素个数，避免手动填写长度出错。

#### （5）I2C读操作示例-检测OLED状态

1  uint8_t oled_status;
2  // 从OLED（0x78）读1个字节的状态数据
3  HAL_I2C_Master_Receive(&hi2c1, 0x78, &oled_status, 1, HAL_MAX_DELAY);
4  // 检测状态数据的第6位（D6），判断OLED是否开启
5  if((oled_status & (1<<6)) == 0){
6  // D6=0，OLED开启，点亮PC13 LED
7  HAL_GPIO_WritePin(GPIOC, GPIO_PIN_13, GPIO_PIN_RESET);
8  }else{
9  // D6=1，OLED关闭，熄灭PC13 LED
10  HAL_GPIO_WritePin(GPIOC, GPIO_PIN_13, GPIO_PIN_SET);
11  }

##### 位操作原理

- 1<<6：将数字1左移6位，得到掩码01000000（十进制64），用于定位第6位；
- oled_status & (1<<6)：按位与运算，仅保留第6位，其余位清零；
- 结果为0表示D6=0，结果非0表示D6=1。

### 易错点

7. OLED从机地址填写错误（将0x78写成0x7A，未匹配硬件SA0引脚）；
8. 命令流未加0x00指令标识，导致OLED无法识别指令；
9. 位操作时移位位数错误（如将第6位写成1<<5），导致状态判断错误。

# 四、时钟树系统

时钟树是STM32的核心“心脏”，为所有外设（GPIO、UART、I2C、SPI）和内核提供不同频率的时钟信号，决定了芯片的运行速度和外设工作效率，STM32F103的内核最大时钟频率为72MHz。

## 4.1 核心定义与设计需求

### 核心定义

时钟树是由晶振、倍频器（PLL）、分频器组成的时钟分配系统，将原始晶振频率转换为不同频率的时钟信号，分配给内核、AHB总线、APB总线和各个外设。

### 设计需求（核心）

STM32内部不同模块对时钟频率的要求不同，如：

- 内核（Cortex-M3）：最高72MHz，决定代码执行速度；
- APB2总线：最高72MHz（驱动GPIO、USART1、SPI1等高速外设）；
- APB1总线：最高36MHz（驱动I2C、USART2/3等低速外设）；
- 实时时钟（RTC）：32.768kHz（低功耗、高精度）；

因此需要时钟树实现频率的倍频/分频，按需分配。

### 时序逻辑vs组合逻辑（时钟的作用）

1. 组合逻辑：无记忆元件，输出仅由当前输入决定，无需时钟；
2. 时序逻辑：含记忆元件（触发器），必须在时钟脉冲（CP）的触发下工作，STM32所有外设均为时序逻辑，时钟是其工作的前提。

## 4.2 时钟树结构（STM32F103，核心）

时钟树分为树根（时钟源）、树干（倍频/分频核心）、树叶（时钟分配） 三部分，树根为原始时钟源，树干为PLL倍频器，树叶为各总线和外设的分频分配。

### 1. 树根-4个核心时钟源（RCC模块，Reset & Clock Controller）

时钟源名称 | 频率范围 | 特性 | 适用场景
HSI（内部高速） | 8MHz（默认） | 低成本，无需外接硬件，精度一般 | 快速开发、无高精度要求的场景
HSE（外部高速） | 4~16MHz（常用8MHz） | 高精度，需外接晶振/陶瓷振荡器 | 高精度通信、高速运行场景
LSI（内部低速） | 40kHz左右 | 低功耗，精度低 | 看门狗（IWDG）、低功耗模式
LSE（外部低速） | 32.768kHz | 高精度，低功耗，需外接晶振 | 实时时钟（RTC）、日历功能

#### 核心辨析

- HSI vs HSE：开发中优先使用HSE 8MHz，精度高，适配高速通信；HSI仅用于无外接晶振的低成本场景；
- LSI vs LSE：RTC必须使用LSE 32.768kHz，保证时间精度；LSI仅用于看门狗。

### 2. 树干-PLL倍频器（核心）

- 核心定义：锁相环（Phase-Locked Loop），将树根的低频时钟信号倍频为高频信号，作为系统时钟（SYSCLK）的核心；
- 倍频范围：2~16倍，STM32F103的SYSCLK最大为72MHz；
- 分频预处理：HSE/HSI可先进行2分频，再进入PLL倍频（灵活调整频率）。

### 3. 树叶-时钟分配（总线+外设）

系统时钟（SYSCLK）经AHB分频器、APB1/APB2分频器后，分配给各个总线和外设，分频系数可在CubeMX中配置：

总线/模块 | 最大频率 | 分频规则 | 挂载外设
SYSCLK（系统时钟） | 72MHz | 由PLL倍频得到，直接给AHB总线 | 所有总线的时钟源
HCLK（AHB总线） | 72MHz | SYSCLK经AHB分频器得到（默认1分频） | 内核、RAM、FLASH、DMA
PCLK2（APB2总线） | 72MHz | HCLK经APB2分频器得到（默认1分频） | GPIOA~C、USART1、SPI1、TIM1
PCLK1（APB1总线） | 36MHz | HCLK经APB1分频器得到（默认2分频） | I2C1/2、USART2/3、SPI2、TIM2~4

#### 核心结论

- HCLK决定代码执行速度：HCLK为72MHz时，芯片运行速度最快；
- APB1总线频率不可超过36MHz：必须分频（至少2分频），否则外设损坏。

## 4.3 倍频/分频计算与CubeMX配置

### 1. 核心计算公式

系统时钟（SYSCLK）= 时钟源频率 ÷ 预分频系数 × PLL倍频系数

- 预分频系数：仅HSE/HSI支持，可选1或2（默认2）；
- PLL倍频系数：2~16，最大不超过使SYSCLK=72MHz。

### 2. 经典计算示例（STM32F103，HSE 8MHz为时钟源）

#### 示例1：SYSCLK=8MHz（低速运行）

SYSCLK = HSE(8MHz) ÷ 2 × 2 = 8MHz

#### 示例2：SYSCLK=12MHz（中速运行）

SYSCLK = HSE(8MHz) ÷ 2 × 3 = 12MHz

#### 示例3：SYSCLK=72MHz（最高速，开发首选）

SYSCLK = HSE(8MHz) × 9 = 72MHz（预分频系数=1，倍频系数=9）

### 3. CubeMX时钟配置流程（核心，开启HSE+72MHz主频）

1. 打开System Core→RCC（复位和时钟控制器）；
2. 配置时钟源：
  - High Speed Clock (HSE)：选择Crystal/Ceramic Resonator（外接晶振）；
  - Low Speed Clock (LSE)：根据需求选择（无需RTC则Disable）；
3. 打开System Core→SYS，Debug选择Serial Wire（避免占用时钟引脚）；
4. 打开Clock Configuration（时钟配置）：
  - 选择PLL时钟源为HSE；
  - 配置PLL倍频系数为9（8MHz×9=72MHz）；
  - 配置AHB分频器为1（HCLK=72MHz）；
  - 配置APB1分频器为2（PCLK1=36MHz）；
  - 配置APB2分频器为1（PCLK2=72MHz）；
5. 点击Clock Configuration中的Apply，生成时钟初始化代码。

### 易错点

1. 配置72MHz主频时，PLL倍频系数超过9（如10，导致SYSCLK=80MHz，超过芯片最大频率，烧毁外设）；
2. APB1分频器未配置为2分频，导致PCLK1超过36MHz；
3. 未开启HSE却选择PLL时钟源为HSE，导致时钟初始化失败。

## 4.4 基于主频的延时实验（核心实操）

利用时钟频率与指令周期的关系，通过空循环实现简单延时，理解主频对代码执行速度的影响。

### 1. 核心原理

- 时钟频率：表示芯片每秒执行的指令周期数，如8MHz=800万次/秒（1个周期=1/8μs）；
- 空循环for(i=0; i<N; i++);的平均指令周期：约8个周期（不同编译器略有差异，入门阶段简化为8个）；
- 延时公式：延时时间 ≈ (N × 8) / 时钟频率（Hz）。

### 2. 实验示例-8MHz主频实现1秒延时

- 8MHz时钟：1个周期=1/8μs，8个周期=1μs；
- 1秒=100万μs，因此需要100万次空循环（100万×1μs=1秒）；
- 核心代码（LED以2秒为周期闪烁：1秒亮，1秒灭）：
1  while(1){
2  // 点亮PC13 LED
3  HAL_GPIO_WritePin(GPIOC, GPIO_PIN_13, GPIO_PIN_RESET);
4  // 1秒延时（100万次空循环）
5  for(uint32_t i=0; i<1000000; i++);
6  // 熄灭PC13 LED
7  HAL_GPIO_WritePin(GPIOC, GPIO_PIN_13, GPIO_PIN_SET);
8  // 1秒延时
9  for(uint32_t i=0; i<1000000; i++);
10  }

### 3. 72MHz主频的延时调整

72MHz=7200万次/秒，8个周期=8/72μs=1/9μs，因此1秒延时需要900万次空循环（900万×1/9μs=1秒）。

### 易错点

1. 未根据主频调整空循环次数（如72MHz主频仍用100万次，导致延时过短）；
2. 循环变量未定义为uint32_t（16位变量最大为65535，无法满足100万次循环）。

# 五、串行通信-SPI

SPI（Serial Peripheral Interface）是四线制同步串行通信总线，支持高速全双工通信，速率远高于UART/I2C，广泛用于外部FLASH、SD卡、触摸屏等高速外设，核心特点是速度快、全双工、协议简单。

## 5.1 核心原理与总线构成

### 1. 总线构成（四线制，主机主导）

SPI为主从架构，一个主机可挂载多个从机，总线由4根线组成（部分场景可简化为三线制，节省NSS引脚）：

引脚名称 | 英文全称 | 核心功能
MOSI | Master Output Slave Input | 主机输出，从机输入（主机向从机发送数据）
MISO | Master Input Slave Output | 主机输入，从机输出（从机向主机发送数据）
SCK | Serial Clock | 串行时钟线，由主机产生，同步数据传输（决定通信速度）
NSS/CS | Slave Select/Chip Select | 从机选择线，低电平有效，主机拉低某从机的NSS，仅与该从机通信（实现多从机挂载）

### 2. 核心特性

- 全双工通信：MOSI和MISO独立，主从可同时收发数据，通信效率高；
- 同步通信：由主机SCK时钟同步，无需波特率，速率远高于异步通信；
- 无地址机制：通过NSS引脚选择从机，协议比I2C简单；
- 速率范围：无固定限制，一般为几Mbps到几十Mbps（远高于I2C/UART）。

### 3. 多从机挂载方式

1. 独立NSS引脚：每个从机分配一个独立的NSS引脚，主机通过拉低对应引脚选择从机（硬件简单，开发首选）；
2. 菊花链：所有从机的NSS引脚串联，实现多从机级联（硬件节省引脚，协议复杂）。

## 5.2 5大通信参数辨析（SPI核心，必须主从一致）

SPI的通信参数直接决定数据传输的正确性，主机与从机的5个参数必须完全一致，否则会出现数据乱码、传输失败，是CubeMX配置的重点。

### 1. 波特率（SCK频率）

- 核心定义：主机产生的SCK时钟频率，即每秒传输的比特数，由主机分频系数决定；
- 配置方式：CubeMX中通过Prescaler（分频系数） 配置，分频系数从2到256可选（如AHB时钟72MHz，分频系数2→波特率36Mbps）；
- 特点：SPI波特率远高于I2C/UART，常用1/4/10Mbps。

### 2. 比特位传输顺序

- MSB First：高位先行（Most Significant Bit），开发首选，绝大多数外设支持；
- LSB First：低位先行（Least Significant Bit），仅少数特殊外设支持；
- 核心：一个字节的8位数据，先传输最高位（bit7）还是最低位（bit0）。

### 3. 数据位长度

- 常用8位（开发首选），部分外设支持16位；
- 主从设备需一致，否则数据传输位数不匹配。

### 4. 时钟极性（CPOL，Clock Polarity）

- 核心定义：SPI总线空闲状态下，SCK时钟线的电平状态；
  - CPOL=0：空闲状态为低电平（开发首选）；
  - CPOL=1：空闲状态为高电平。

### 5. 时钟相位（CPHA，Clock Phase）

- 核心定义：主机/从机采集数据的时刻，即在SCK时钟的第几个边沿（上升沿/下降沿）采集数据；
  - CPHA=0：在SCK的第1个边沿采集数据（开发首选）；
  - CPHA=1：在SCK的第2个边沿采集数据。

### SPI的4种时钟模式（CPOL+CPHA组合，核心）

由时钟极性和相位组合而成，共4种模式，模式0（CPOL=0+CPHA=0）为开发首选，绝大多数外设（如W25QXX外部FLASH）仅支持模式0。

模式编号 | CPOL（极性） | CPHA（相位） | 核心特点
模式0 | 0（低空闲） | 0（第1边沿采集） | 开发首选，外设兼容性最强
模式1 | 0（低空闲） | 1（第2边沿采集） | 少数高速外设支持
模式2 | 1（高空闲） | 0（第1边沿采集） | 工业级外设
模式3 | 1（高空闲） | 1（第2边沿采集） | 特殊高速外设

### 易错点

1. 5大通信参数主从不一致（尤其是时钟模式），导致数据传输乱码；
2. 波特率配置过高，超出从机的最大支持速率（如外部FLASH最大支持10Mbps，配置为36Mbps）。

## 5.3 CubeMX配置与模式选择（Connectivity→SPIx）

### 1. 核心配置步骤

1. 打开Connectivity→SPIx（如SPI1），Mode选择Master（主机模式，开发首选，STM32一般作为主机）；
2. 配置基本参数（Basic Parameters）：
  - Frame Format（帧格式）：Motorola（标准SPI帧格式，开发首选），其余TI/Microwire为特殊格式；
  - Data Size（数据位）：8 Bits；
  - First Bit（传输顺序）：MSB First；
3. 配置时钟参数（Clock Parameters）：
  - Prescaler（分频系数）：根据需求选择（如2，波特率36Mbps）；
  - Clock Polarity (CPOL)：Low（模式0）；
  - Clock Phase (CPHA)：1 Edge（模式0）；
4. 配置高级参数（Advanced Parameters）：
  - NSS Signal Type（NSS类型）：Software（软件控制NSS，开发首选），Hardware为硬件控制（极少使用）；
  - CRC Calculation：Disabled（关闭CRC校验，简化通信）；
5. 配置NSS引脚：软件控制NSS时，需手动指定一个GPIO引脚作为NSS（如PA4），配置为推挽输出。

### 2. NSS引脚的软件控制（核心）

- 硬件NSS：由SPI外设自动控制，仅支持单从机，极少使用；
- 软件NSS：由用户通过GPIO函数手动拉低/拉高NSS引脚，灵活支持多从机，步骤为：
  a. 拉低NSS引脚：HAL_GPIO_WritePin(GPIOA, GPIO_PIN_4, GPIO_PIN_RESET);（选中从机，开始通信）；
  b. 执行SPI读写操作；
  c. 拉高NSS引脚：HAL_GPIO_WritePin(GPIOA, GPIO_PIN_4, GPIO_PIN_SET);（取消选中，结束通信）。

### 易错点

1. 帧格式选择错误（如TI格式），而非标准Motorola格式；
2. 软件控制NSS时，忘记拉高/拉低引脚，导致从机未被选中或一直被选中；
3. NSS引脚未配置为推挽输出，导致无法有效控制从机。

## 5.4 实操实验-外部FLASH（W25QXX）操作

### 1. 硬件接线（STM32F103C8TX + W25QXX）

- W25QXX的VCC→3.3V，GND→GND；
- W25QXX的MOSI→STM32 SPI1_MOSI（PA7）；
- W25QXX的MISO→STM32 SPI1_MISO（PA6）；
- W25QXX的SCK→STM32 SPI1_SCK（PA5）；
- W25QXX的CS→STM32 PA4（软件NSS，推挽输出）。

### 2. 核心操作-按键控制FLASH读写

通过PA0引脚的按键，实现按键按下时向FLASH写数据，松开时读数据，核心是按键消抖和SPI读写配合NSS控制。

#### （1）按键消抖（核心，机械按键必备）

采用状态检测法，通过保存按键的上一次状态（pre） 和当前状态（cur），仅当状态发生变化时才执行操作，避免电平抖动导致误判：

1  uint8_t pre = 1; // 上一次按键状态（初始为松开，高电平）
2  uint8_t cur = 1; // 当前按键状态
3  while(1){
4  pre = cur; // 更新上一次状态
5  // 读取当前按键状态（PA0，上拉输入）
6  cur = HAL_GPIO_ReadPin(GPIOA, GPIO_PIN_0) == GPIO_PIN_SET ? 1 : 0;
7  // 仅当状态发生变化时执行操作
8  if(pre != cur){
9  if(cur == 0){
10  // 按键按下：拉低NSS，向FLASH写数据
11  HAL_GPIO_WritePin(GPIOA, GPIO_PIN_4, GPIO_PIN_RESET);
12  // 执行SPI写操作（如写入0x5A）
13  // ...
14  HAL_GPIO_WritePin(GPIOA, GPIO_PIN_4, GPIO_PIN_SET);
15  }else{
16  // 按键松开：拉低NSS，从FLASH读数据
17  HAL_GPIO_WritePin(GPIOA, GPIO_PIN_4, GPIO_PIN_RESET);
18  // 执行SPI读操作
19  // ...
20  HAL_GPIO_WritePin(GPIOA, GPIO_PIN_4, GPIO_PIN_SET);
21  }
22  }
23  }

### 易错点

1. 操作FLASH时未先拉低NSS引脚，导致从机未被选中，读写失败；
2. 读写完成后未拉高NSS引脚，导致从机一直处于选中状态，影响后续通信；
3. 未做按键消抖，导致按键按下时多次执行读写操作。

# 六、通用易错点与核心辨析汇总

## 6.1 通用易错点（所有模块均需注意）

1. 引脚配置错误：如将I2C的SCL/SDA配置为推挽输出，而非开漏输出；
2. 外设句柄使用错误：如将huart1写成huart2，或忘记加取地址符&；
3. 数据类型不匹配：如将char直接传入要求uint8_t的函数，未做强制类型转换；
4. 主从参数不一致：UART的波特率、I2C的速率、SPI的时钟模式，主从必须完全一致；
5. 头文件缺失：如使用strlen函数未包含string.h，使用uint32_t未包含stdint.h；
6. 变量类型溢出：如用uint16_t定义100万次循环的变量，导致溢出。

## 6.2 核心概念辨析（易混淆点）

### 1. 开漏输出vs推挽输出

- 开漏输出：仅控N-MOS，高电平需上拉，支持线与逻辑，用于I2C/SPI总线；
- 推挽输出：控P-MOS+N-MOS，直接输出高低电平，不支持线与，用于普通GPIO输出。

### 2. UART vs USART vs I2C vs SPI

特性 | UART/USART | I2C | SPI
引脚数 | 2（TX/RX） | 2（SCL/SDA） | 4（MOSI/MISO/SCK/NSS）
通信方式 | 异步/同步 | 同步 | 同步
全双工 | 是 | 是（半双工） | 是（全双工）
速率 | 低（≤115200bps） | 中（≤400kbps） | 高（几Mbps~几十Mbps）
多从机 | 需地址帧 | 支持（地址） | 支持（NSS）
核心应用 | 电脑调试、蓝牙 | OLED、传感器 | 外部FLASH、SD卡

### 3. 时钟源HSI vs HSE

- HSI：内部8MHz，低成本，无需外接硬件，精度一般；
- HSE：外部4~16MHz，高精度，需外接晶振，开发首选。

### 4. SPI的4种时钟模式

- 模式0（CPOL=0+CPHA=0）：空闲低电平，第1边沿采集，开发首选；
- 其余模式仅适用于特殊外设，需严格匹配从机手册。

### 5. 应答（ACK/NAK）-I2C核心

- ACK：从机拉低SDA，表示地址匹配/数据接收完成；
- NAK：从机不拉低SDA，表示地址不匹配/数据接收失败，通信终止。

## 6.3 开发核心原则

1. 硬件为先：所有外设操作前，先确认硬件接线和引脚配置，再写代码；
2. 参数一致：主从通信的所有参数

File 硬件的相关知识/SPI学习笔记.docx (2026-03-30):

SPI学习笔记

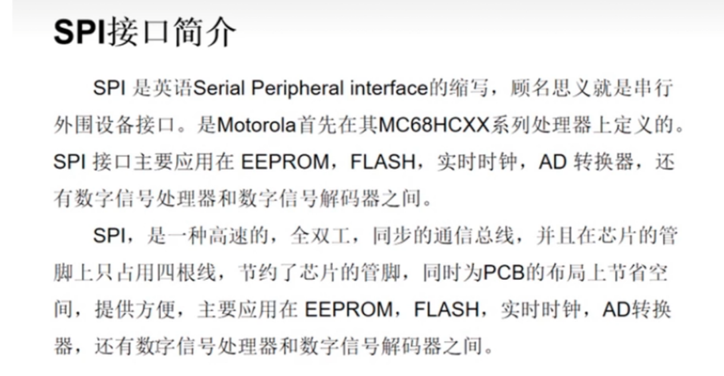
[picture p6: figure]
3ILP4PZGADQCY

硬件结构：

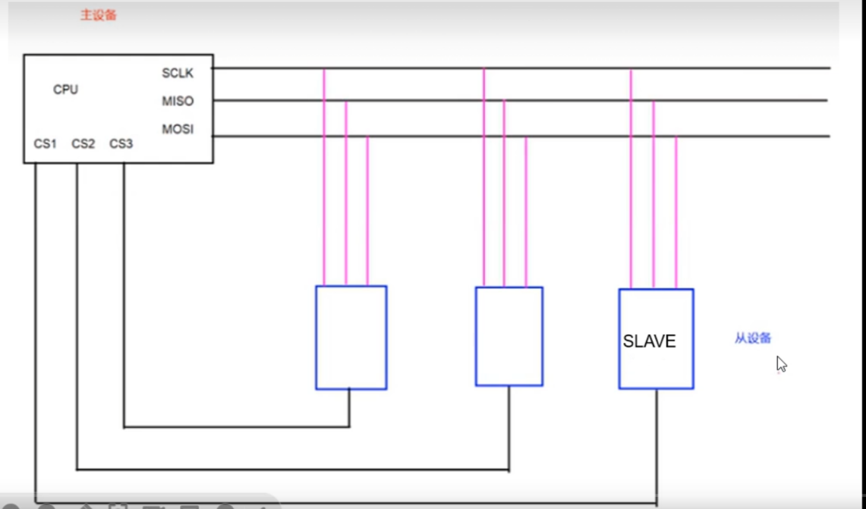
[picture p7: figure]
62374PZGAAQCA

SPI 是同步、全双工、主从式通信：

- 主机 ---从机
- SCK：时钟
- MOSI：主机发 → 从机收
- MISO：从机发 → 主机收

MOSI/MISO 都是推挽输出（Push-Pull）：

- 芯片内部电路直接强驱动高电平 / 低电平
- 不需要外部上拉来 “帮忙拉高”

### 以 W25Qxx 系列 SPI Flash 为例

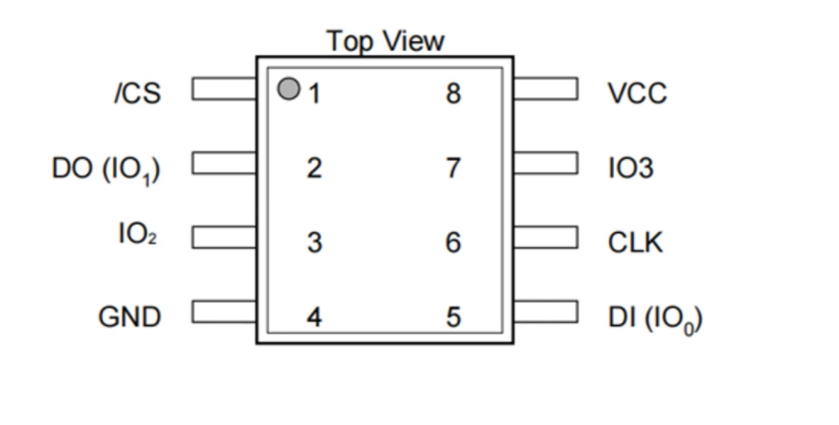
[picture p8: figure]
6HDAKQBGADACA

这是典型的 8 引脚 SPI/Quad SPI Flash 引脚定义，按引脚号逐一说明：

引脚号 | 引脚名 | 功能详细说明
1 | /CS | 片选信号（低电平有效） • 主机拉低：选中当前芯片，开始通信 • 主机拉高：芯片进入待机状态，忽略 SCK/MOSI 等信号 • 必须在通信前后正确拉抬，否则会导致总线冲突
2 | DO (IO1) | 数据输出 / 双向 IO1 • 标准 SPI 模式：作为 MISO，从机向主机发送数据 • QPI/Quad SPI 模式：作为双向 IO 口，用于高速读写
3 | IO2 | 双向 IO2 • 标准 SPI 模式：通常作为写保护（/WP）引脚，控制芯片是否允许写入 • Quad SPI 模式：作为第 3 条数据总线，提升传输速度
4 | GND | 电源地 • 必须可靠连接到系统地，是芯片正常工作的基础
5 | DI (IO0) | 数据输入 / 双向 IO0 • 标准 SPI 模式：作为 MOSI，主机向从机发送数据 • QPI/Quad SPI 模式：作为双向 IO 口，是核心数据通道
6 | CLK | 串行时钟 • 由主机提供，同步所有数据传输 • 数据在时钟的上升沿/下降沿采样，具体由 SPI 模式决定
7 | IO3 | 双向 IO3 • 标准 SPI 模式：通常作为保持（/HOLD）引脚，暂停当前通信而不取消片选 • Quad SPI 模式：作为第 4 条数据总线，实现 4 线高速传输
8 | VCC | 电源正 • 典型电压 2.7V~3.6V（具体看芯片型号），需配合去耦电容（0.1µF）滤除噪声

### 二、关键符号与模式区分详解

#### 1. /CS 与 CS 的区别

- /CS：斜杠（或横线）表示低电平有效（Active Low）
  - 逻辑 0（低电平）：芯片被选中，响应通信
  - 逻辑 1（高电平）：芯片休眠，不响应任何信号
- CS：无斜杠表示高电平有效（Active High）
  - 逻辑 1（高电平）：芯片被选中
  - 逻辑 0（低电平）：芯片休眠
- ***实际嵌入式中，绝大多数 SPI 设备的片选都是 /CS（低有效），这是行业惯例。

#### 2. 标准 SPI 模式 vs Quad SPI 模式

引脚 | 标准 SPI 模式（3线+片选） | Quad SPI/QPI 模式（4线+片选）
DI (IO0) | MOSI（主机→从机） | 双向数据 IO0
DO (IO1) | MISO（从机→主机） | 双向数据 IO1
IO2 | /WP（写保护） | 双向数据 IO2
IO3 | /HOLD（暂停通信） | 双向数据 IO3
优势 | 兼容性好，电路简单 | 4 线并行传输，速度大幅提升
适用场景 | 低速、简单通信 | 高速数据读写（如固件更新）

#### 3. /WP 与 /HOLD 的特殊功能

- /WP（IO2）：写保护引脚（低电平有效）
  - 拉低：禁止对芯片的扇区/块/芯片擦除、编程操作，防止误写
  - 拉高：允许正常写入操作
- /HOLD（IO3）：保持引脚（低电平有效）
  - 拉低：暂停当前 SPI 传输，保持寄存器状态，不取消片选
  - 拉高：恢复之前的传输
  - 适用于多主机共享总线时的临时抢占

### 三、与传统 SPI 引脚的对应关系

传统 SPI 引脚 | 本芯片对应引脚 | 说明
NSS（/CS） | 引脚 1 /CS | 片选，低有效
SCK | 引脚 6 CLK | 串行时钟
MOSI | 引脚 5 DI | 主机发送，从机接收
MISO | 引脚 2 DO | 从机发送，主机接收

### 四、工程实践建议

1. 片选 /CS：必须由主机 GPIO 控制，通信前拉低，结束后立即拉高，避免干扰其他设备。
2. 电源去耦：在 VCC 与 GND 之间就近放置 0.1µF 陶瓷电容，提升电源稳定性。
3. 模式选择：
  - 新手/简单项目：使用标准 SPI 模式，将 /WP 和 /HOLD 上拉到 VCC，避免误触发。
  - 高速需求：使用 Quad SPI 模式，将 IO2/IO3 配置为数据总线，需在软件中开启 QPI 模式。

CPOL、CPHA 是 SPI 里的「时钟相位/极性」，决定 SPI 怎么读数据、什么时候读。

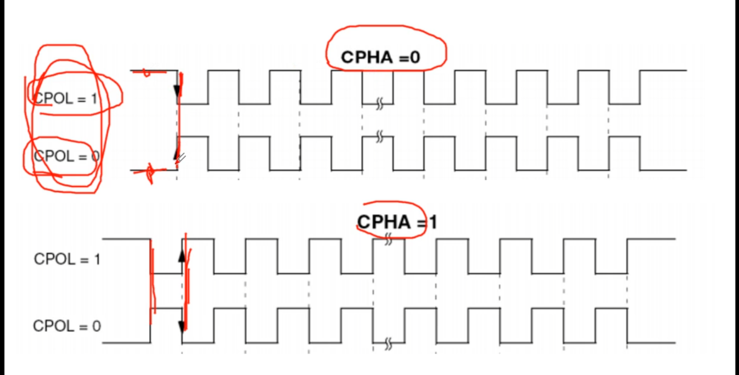
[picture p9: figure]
RTE2CQBGAAAAW

# 1.CPOL和CPHA是干嘛的

- CPOL：Clock Polarity —— 时钟空闲时是高还是低
- CPHA：Clock Phase —— 在第几个边沿采样数据

你可以理解成：

SPI 通信双方必须用「同一种说话节奏」，CPOL+CPHA 就是定这个节奏。

# 2. 拆开讲

### ① CPOL（时钟极性）

- CPOL=0：空闲时 SCK（时钟线）= 低电平
- CPOL=1：空闲时 SCK = 高电平

只决定：不通信的时候，时钟线是静息在高还是低。

### ② CPHA（时钟相位）

决定：数据是在时钟的「第一个边沿」还是「第二个边沿」被读取

- CPHA=0：在第一个跳变沿采样
- CPHA=1：在第二个跳变沿采样

# 3. 组合起来就是 4 种 SPI 模式（最常用就两种）

- 模式0：CPOL=0，CPHA=0
- 模式1：CPOL=0，CPHA=1
- 模式2：CPOL=1，CPHA=0
- 模式3：CPOL=1，CPHA=1

90% 器件用：模式0 或 模式3

# 4. 这俩到底有啥用？

非常有用，而且必须懂，不然你 SPI 永远会遇到：

- 读出来乱码
- 数据不对
- 调试半天不知道为啥

原因只有一个：

主机和从机的 CPOL/CPHA 必须一模一样，否则通信直接炸。

你可以把它类比成：

- 两个人说话
- 一个说“我在上升沿说话”
- 一个说“我在下降沿听”

→ 那肯定听不清啊！

CPOL、CPHA 就是统一“什么时候说、什么时候听”。

# 5. 最实用结论（你记这个就够）

4. SPI 能不能通，第一步就是看 CPOL、CPHA 对不对
1. 大多数传感器、Flash、OLED、SPI 屏：
  - 要么 模式0（0,0）
  - 要么 模式3（1,1）
2. 你在 CubeMX 里配置 SPI，这两个参数必须和芯片手册一致，不一致就废。

写使能

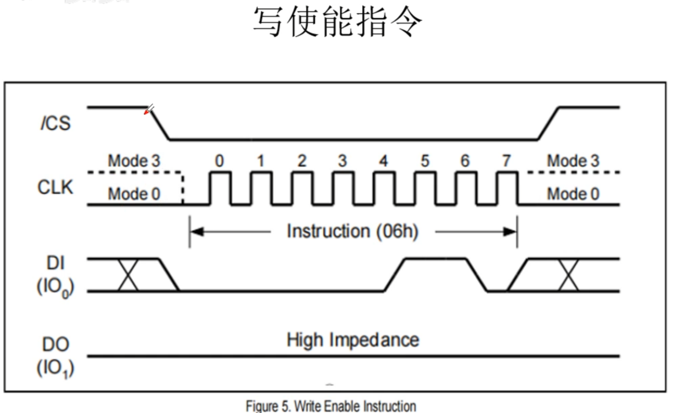
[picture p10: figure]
HGHKWQBGABADQ

# 1. 先说 I2C

I2C 确实是：只在 SCL 高电平时，采样数据。

- SCL 高：读数据（0 或 1）
- SCL 低：主机 / 从机改数据

只有 SCL 高的时候读，低的时候不改读， I2C 是完全正确的。

# 二、重点：SPI 不是这样！

SPI 看的是 边沿：上升沿 / 下降沿不是看 “高电平期间”。

你刚才那套理解，放到 SPI 就错了。

我用最简单的话讲：

### SPI 里：

数据只在时钟 “跳变那一下” 被采样，不是高电平期间一直读。

- 上升沿：0 → 1 那一下
- 下降沿：1 → 0 那一下

就一瞬间，不是整个高电平。

# 读状态寄存器

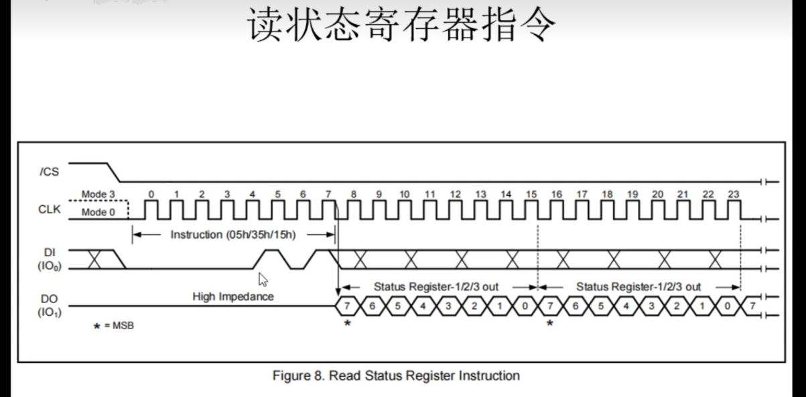
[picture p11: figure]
YEN36QBGABQH4
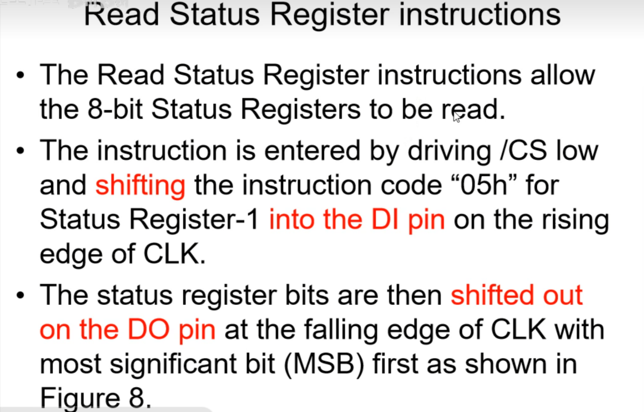
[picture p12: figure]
3BM5EQBGADADY

这张图是 W25Q Flash 芯片手册里关于 ** 读状态寄存器（Read Status Register）** 的说明，非常关键。我给你逐句翻译，结合你刚才学的 SPI 知识，让你一眼看懂它到底在干嘛。

### 1. 第一句：干啥用的？

"The Read Status Register instructions allow the 8-bit Status Registers to be read."

- 翻译：这个指令允许 CPU 读取芯片内部的 8 位状态寄存器。
- 人话：状态寄存器里存着芯片的 “身份证” 和 “当前状态”（比如是不是正在擦写、写保护有没有开）。你可以通过这个指令把这些信息读出来检查。

### 2. 第二句：怎么发指令？（重点！）

"The instruction is entered by driving /CS low and shifting the instruction code “05h” for Status Register-1 into the DI pin on the rising edge of CLK."

- 翻译：拉低 CS 片选线选中芯片，然后在时钟的 上升沿，把指令码 05h（二进制 0000 0101）通过 DI 引脚（也就是 MOSI）移位进去。
- 结合你的知识：
  - 这明确指出了指令是在上升沿发送的。
  - 所以配合这个指令，SPI 模式通常是 CPOL=0, CPHA=0（模式 0），因为模式 0 就是在上升沿采样。

### 3. 第三句：怎么收数据？（重点！）

"The status register bits are then shifted out on the DO pin at the falling edge of CLK with most significant bit (MSB) first..."

- 翻译：然后，状态寄存器的数据位会在时钟的 下降沿，从 DO 引脚（也就是 MISO）移位出来。先发高位（MSB）。
- 结合你的知识：
  - 数据接收是在下降沿！
  - 这一点非常重要：你发指令时看上升沿，收数据时看下降沿。

### 📝 总结成一套动作（你记这个就行）

1. 拉低 CS：开始说话。
2. 发指令 05h：
  - 在 SCK 上升沿 发。
  - 走 DI（MOSI）线。
3. 收数据：
  - 芯片在 SCK 下降沿 把数据推到 DO（MISO）线上。
  - 先发高位，一共发 8 个时钟周期。
4. 拉高 CS：结束通话。

这张图再次验证了：W25Q 是标准的 SPI 模式 0（上升沿读指令，下降沿出数据）。

要不要我给你写一段基于 HAL 库的 W25Q 读状态寄存器 代码？你可以直接对照这个时序看代码是怎么运行的。

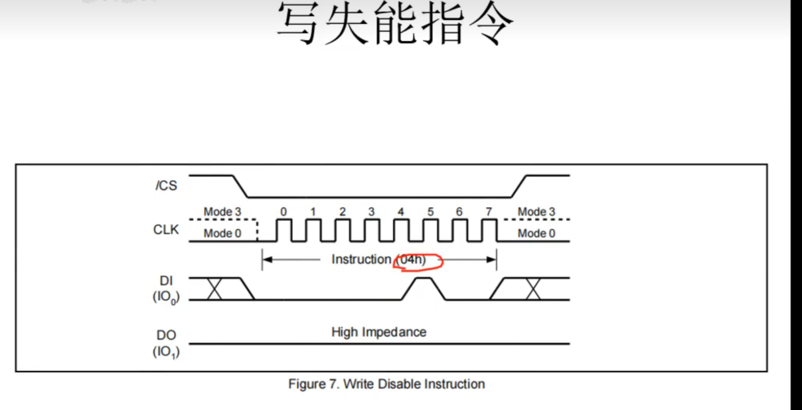
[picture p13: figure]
TQOAAQJGAAAE4
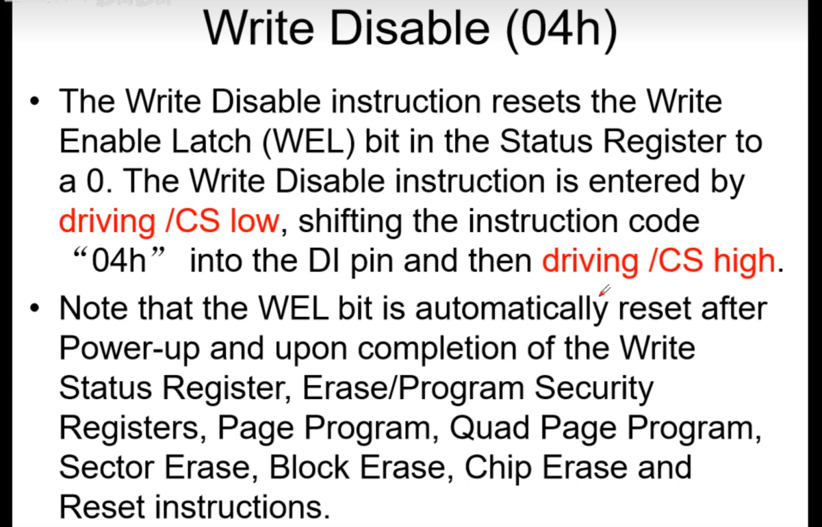
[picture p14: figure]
KVNAAQJGADQGA
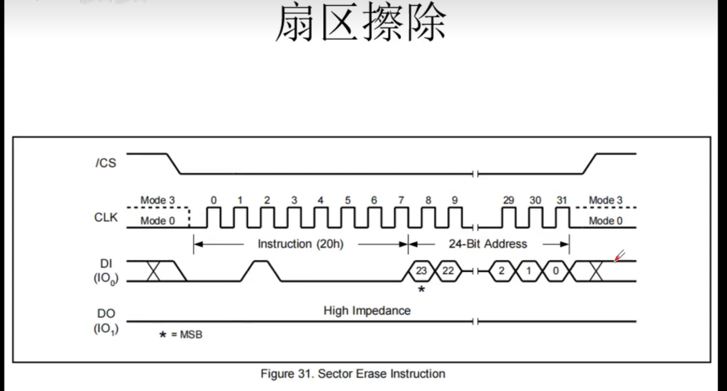
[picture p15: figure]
EGRAAQJGADQCY
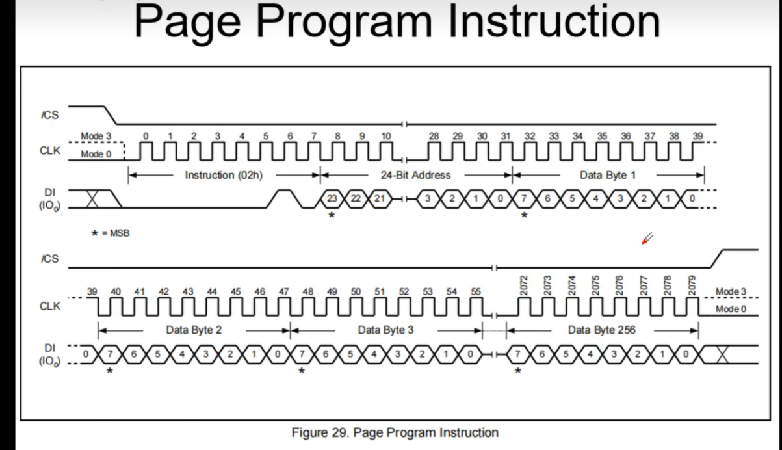
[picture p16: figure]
HTVAAQJGABQH4

# W25Qxx Flash 学习重点

5. 硬件连接与 SPI 模式
- 接线：
- SCK / MOSI / MISO / CS（片选，必须拉低才能通信）
- VCC（3.3V，严禁 5V）、GND
- 可选：WP（写保护）、HOLD（暂停）
- SPI 模式：

W25Qxx 固定支持 Mode 0（CPOL=0, CPHA=0） 和 Mode 3（CPOL=1, CPHA=1），STM32 里要对应配置好。

# 1. 存储结构（核心！）

W25Qxx 是页-扇区-块-芯片的分层结构，以 W25Q128（128Mbit=16MB）为例：

- 页（Page）：最小编程单位，256 字节
- 扇区（Sector）：最小擦除单位，4KB（4096 字节）
- 块（Block）：更大擦除单位，32KB / 64KB 两种
- 芯片：整片擦除

⚠️ 关键：不能单字节改写，必须先擦除（扇区/块/整片）再编程，擦除后所有位变为 1。

# 2. 核心指令集（必须掌握）

指令 功能 关键细节

0x06 Write Enable 写操作前必须发，解锁写保护

0x04 Write Disable 锁定写保护

0x05 Read Status Register 查 BUSY 位，判断操作是否完成

0x03 Read Data 标准读，支持任意地址

0x0B Fast Read 高速读，需 dummy 字节

0x02 Page Program 页编程，最多 256 字节，不能跨页

0x20 Sector Erase 4KB 扇区擦除

0xD8 Block Erase 64KB 块擦除

0xC7 Chip Erase 整片擦除（耗时久，谨慎用）

0x9F Read JEDEC ID 读芯片 ID（厂商+设备 ID），用于识别型号

# 3. 典型操作流程

## 读数据：

1. 拉低 CS

2. 发 0x03 （读指令）

3. 发 24 位目标地址

4. 连续读 N 个字节

5. 拉高 CS

## 页编程（写数据）：

1. 拉低 CS → 发 0x06 （写使能）→ 拉高 CS

2. 拉低 CS → 发 0x02 （页编程指令）→ 发 24 位地址 → 发最多 256 字节数据 → 拉高 CS

3. 循环读状态寄存器 0x05 ，直到 BUSY 位为 0（操作完成）

## 扇区擦除：

1. 拉低 CS → 发 0x06 （写使能）→ 拉高 CS

2. 拉低 CS → 发 0x20 （扇区擦除指令）→ 发 24 位扇区首地址 → 拉高 CS

3. 等待 BUSY 位清 0

# 4. 关键注意事项

- 写保护：
- 状态寄存器有块保护位（BP0-BP3），可锁定部分区域不被擦写
- WP 引脚拉低可进一步锁定状态寄存器
- HOLD 功能：
- 拉低 HOLD 可暂停通信，适合多主机共享总线场景
- 可靠性：
- 擦写次数：典型 10 万次
- 数据保存：20 年以上
- 编程/擦除时不能断电，否则可能损坏数据

# 5. 工程实践建议

1. 先读 ID 验证：上电后先发 0x9F 读 JEDEC ID，确认芯片型号和通信正常

2. 封装操作函数：把读/写/擦除封装成函数，避免重复写 SPI 底层

3. 地址对齐：编程时尽量按页对齐，擦除按扇区对齐，提高效率

4. 容错处理：每次写/擦后检查 BUSY 位，超时处理异常

5. 避免频繁擦写：设计时尽量批量写入，减少擦除次数

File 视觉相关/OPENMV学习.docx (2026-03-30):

OPENMV学习

先说明：OpenMV 用的是自家 image 库，不是 OpenCV，只是视觉思路和 OpenCV 类似，我会按你给的逻辑，把完整代码逐句拆解+逐行注释，先给通用完整代码，再逐句精讲每个函数/语句。

# 一、完整代码

1  # 1. 导入OpenMV内置库
2  import sensor, image, time
4  # 2. 测距核心参数（先按你校准的焦距填！）
5  REAL_WIDTH = 5.0 # 正方形真实宽度：5 cm
6  FOCAL_LENGTH = 0.0 # 校准后填这里，例：240.0
7  BLACK_THRESH = (0, 30) # 黑色阈值(LAB亮度)，用阈值编辑器修改
9  # 3. 初始化摄像头
10  sensor.reset()
11  sensor.set_pixformat(sensor.GRAYSCALE) # 灰度图，更快
12  sensor.set_framesize(sensor.QVGA) # 分辨率320×240
13  sensor.skip_frames(time = 2000) # 跳过启动帧，稳定曝光
14  clock = time.clock() # 帧率时钟
16  # 4. 主循环
17  while(True):
18  clock.tick() # 计时
19  img = sensor.snapshot() # 取一帧画面
20  # 找黑色色块
21  blobs = img.find_blobs([BLACK_THRESH], pixels_threshold=200, area_threshold=200)
22  for blob in blobs:
23  w = blob.w() # 色块像素宽度
24  h = blob.h() # 色块像素高度
25  ratio = w / h # 宽高比
26  # 宽高比0.8-1.2，判定为正方形
27  if 0.8 <= ratio <= 1.2:
28  # 相似三角形算距离
29  distance = (REAL_WIDTH * FOCAL_LENGTH) / w
30  # 画矩形框
31  img.draw_rectangle(blob.rect(), color = 255)
32  # 标距离(保留2位小数)
33  img.draw_string(blob.x(), blob.y() - 10, "%.2f cm" % distance, color = 255)
34  # 打印帧率
35  print(clock.fps())

# 二、逐行/逐句精讲（对应代码行+功能+函数含义）

## 模块导入部分

1. import sensor, image, time

导入OpenMV三大核心内置库：sensor管摄像头、image管图像处理、time管计时/延时。

## 参数定义部分

1. REAL_WIDTH = 5.0

定义目标真实物理宽度，单位厘米，固定为5cm正方形。

2. FOCAL_LENGTH = 0.0

存储校准后的镜头焦距，测距核心参数，需用你算的数值替换。

3. BLACK_THRESH = (0, 30)

黑色的LAB颜色阈值，(最小值, 最大值)，用于筛选黑色区域。

## 摄像头初始化

1. sensor.reset()

重置摄像头外设，初始化硬件。

2. sensor.set_pixformat(sensor.GRAYSCALE)

设置图像格式为灰度图，比彩色运算更快，适合黑白目标识别。

3. sensor.set_framesize(sensor.QVGA)

设置分辨率为320×240，平衡识别精度与运行速度。

4. sensor.skip_frames(time = 2000)

跳过2000ms的启动帧，让摄像头曝光、白平衡稳定。

5. clock = time.clock()

创建时钟对象，用于计算、打印实时帧率。

## 主循环

1. while(True):

无限循环，持续采集+处理图像。

2. clock.tick()

每轮循环开始计时，为后续算帧率做准备。

3. img = sensor.snapshot()

拍摄一帧图像，返回image对象，所有图像处理都基于这个img。

### 核心识别：找色块

1. blobs = img.find_blobs([BLACK_THRESH], pixels_threshold=200, area_threshold=200)
  - 函数：image.find_blobs() → OpenMV查找连通色块的核心函数
  - 参数1：阈值列表[BLACK_THRESH] → 只找黑色区域
  - 参数2：pixels_threshold → 过滤像素数过少的噪点
  - 参数3：area_threshold → 过滤面积过小的干扰块
  - 返回值：blobs是色块对象列表，每个元素是一个识别到的黑色块。
2. for blob in blobs:

遍历所有找到的黑色色块，逐个判断是否是正方形。

### 正方形筛选

1. w = blob.w()

调用色块对象的w()方法，获取色块的像素宽度。

2. h = blob.h()

调用h()方法，获取色块的像素高度。

3. ratio = w / h

计算宽高比，用于判断是否接近正方形。

4. if 0.8 <= ratio <= 1.2:

宽高比在0.8~1.2之间，判定为正方形，过滤长方形/长条干扰。

### 相似三角形测距

1. distance = (REAL_WIDTH * FOCAL_LENGTH) / w

相似三角形测距公式：

实际距离 = (真实宽度 × 焦距) ÷ 图像中像素宽度

结果单位：厘米。

### 画面绘制

1. img.draw_rectangle(blob.rect(), color = 255)
  - 函数：image.draw_rectangle() → 画矩形框
  - 参数：blob.rect() → 色块的(x,y,w,h)元组，定位框的位置
  - color=255 → 灰度图中白色线条。
2. img.draw_string(blob.x(), blob.y() - 10, "%.2f cm" % distance, color = 255)
  - 函数：image.draw_string() → 在图像上打印文字
  - 位置：blob.x(), blob.y()-10 → 方框上方10像素，避免遮挡
  - 内容：%.2f → 距离保留2位小数
  - 颜色：白色。

### 帧率输出

1. print(clock.fps())

打印当前运行帧率，判断程序是否流畅。

# 三、焦距校准代码补充（你提到的校准步骤）

1  # 校准专用：只运行一次，测20cm处正方形像素宽度
2  import sensor, image, time
3  sensor.reset()
4  sensor.set_pixformat(sensor.GRAYSCALE)
5  sensor.set_framesize(sensor.QVGA)
6  sensor.skip_frames(2000)
7  while(True):
8  img = sensor.snapshot()
9  blobs = img.find_blobs([(0,30)])
10  for b in blobs:
11  print("像素宽度：", b.w()) # 串口打印像素宽，代入算焦距

焦距公式：

$$ F = \frac{实测距离(cm) \times 像素宽度}{真实宽度(5cm)} $$

例：20cm处像素宽60 → $F=240$，填回FOCAL_LENGTH = 240即可。

# 四、关键函数速记表

好的，我帮你把这个测距例程里用到的所有 OpenMV 官方函数，按初始化、主循环和工具类三类，把它们的函数原型、参数、作用和底层逻辑都梳理清楚，让你彻底看懂每一行代码。

## 一、导入库

1  import sensor, image, time

这是导入 OpenMV 内置的三个核心库：

- sensor：控制摄像头硬件，负责配置和获取图像。
- image：处理图像帧，提供找色块、画图形等功能。
- time：提供计时、延时等工具函数。

## 二、摄像头初始化函数

### 1. sensor.reset()

- 原型：sensor.reset(hard_reset=True)
- 参数：hard_reset（布尔值，默认 True），控制是硬件复位还是软件复位。

TRUE 和默认是软件复位，FULSE是硬件用于卡死复位

- 作用：重置摄像头硬件，初始化 I2C 通信，让摄像头回到初始状态。
- 底层逻辑：拉低摄像头的复位引脚，重启摄像头芯片，然后重新建立 I2C 连接，为后续配置做准备。

### 2. sensor.set_pixformat(pixformat)

- 原型：sensor.set_pixformat(pixformat)
- 参数：pixformat 为像素格式常量，如灰度： sensor.GRAYSCALE 或 彩色：sensor.RGB565。
- 作用：设置摄像头输出的图像格式，这里用灰度图是为了更快的运算速度。

不写的话默认就是彩色

- 底层逻辑：通过 I2C 向摄像头芯片写入寄存器值，切换其内部的图像编码模式。

### 3. sensor.set_framesize(framesize)

- 原型：sensor.set_framesize(framesize)
- 参数：framesize 为分辨率常量，如 sensor.QVGA (320×240)、sensor.VGA (640×480)。
- 作用：设置摄像头输出图像的分辨率，平衡识别精度和运行速度。
- 底层逻辑：通过 I2C 配置摄像头的水平/垂直窗口寄存器，让芯片只输出指定区域的图像。

### 4. sensor.skip_frames(time=2000)

- 原型：sensor.skip_frames(time=2000, number=None)
- 参数：
  - time：跳过的时间（毫秒），默认 2000ms。
  - number：跳过的帧数（可选，设置后 time 失效）。
- 作用：跳过摄像头启动初期不稳定的帧，让自动曝光和白平衡算法稳定下来。
- 底层逻辑：持续读取并丢弃图像数据，直到达到设定的时间或帧数。
- 注意：因为默认是number，所以不写time=的话就是跳过2000帧了

### 5. time.clock()

- 原型：time.clock()
- 作用：创建一个时钟对象，用于计算代码运行的帧率（FPS）。
- 使用：通过 clock.tick() 记录时间点，clock.fps() 获取帧率。

#### 具体解释：

是滑动平均帧率，不是单帧算一次。

#### 具体工作流程

1. clock = time.clock()：创建帧率统计器，初始化计时
2. clock.tick()：记录当前帧的开始时刻，并和上一帧tick()的时间做差，得到单帧耗时
3. 内部会缓存最近多帧的耗时，算平均帧率，不是只看当前一帧
4. clock.fps()：返回计算好的平均 FPS = 1秒 / 平均单帧耗时

#### 举个例子

- 单帧耗时 33ms → 平均帧率 ≈ 30 FPS
- 单帧耗时 50ms → 平均帧率 ≈ 20 FPS

#### 关键总结

- 不是“某一帧开始到结束”，是连续帧之间的时间差
- 是平均帧率，比单帧瞬时值更稳定
- 纯测速工具，和系统时间戳、程序运行总时间无关

## 三、主循环核心函数

### 1. sensor.snapshot()

- 原型：sensor.snapshot()
- 作用：从摄像头获取一帧图像，返回一个 image.Image 对象。
- 底层逻辑：从摄像头的 FIFO 缓冲区读取图像数据，并封装成 image.Image 对象供后续处理。

### 2. img.find_blobs()

- 原型：img.find_blobs(thresholds, pixels_threshold=10, area_threshold=10, merge=False, margin=0, roi=None)
- 参数：
  - thresholds：颜色阈值列表，这里是 [BLACK_THRESH]，即黑色的亮度范围。
  - pixels_threshold：色块的最小像素数，过滤噪点。
  - area_threshold：色块的最小面积，过滤小色块。
- 作用：在图像中寻找符合颜色阈值的色块，返回一个 image.Blob 对象列表。
- 底层逻辑：通过阈值分割找到连通的像素区域，并计算每个区域的几何特征（宽、高、中心等）。

#### 有关该函数参数详细解释：

img.find_blobs() 是 OpenMV 颜色色块识别的核心函数，参数分必填阈值、可选过滤、输出控制三类，我按调用顺序全列清，附含义和常用值。

##### 函数完整原型

1  img.find_blobs(thresholds,
2  x_stride=2, y_stride=1,
3  invert=False,
4  area_threshold=10,
5  pixels_threshold=10,
6  merge=False,
7  margin=0,
8  merge_func=None)

##### 一、必填参数

###### 1. thresholds

- 作用：颜色阈值数组，定义要追踪的颜色范围
- 格式：[ (l_min, l_max, a_min, a_max, b_min, b_max), ... ]（LAB空间）
- 示例：追踪红色 thresholds = [(30, 100, 15, 127, 15, 127)]
- 可传多个阈值，同时识别多种颜色

###### 那具体的格式里面6个参数啥意思

这6个数字是 LAB颜色空间的阈值范围，每组代表：

(L_min, L_max, A_min, A_max, B_min, B_max)

1. L_min / L_max
  - L：亮度(Lightness)
  - 范围：0～100
  - 含义：保留亮度在这两个数之间的像素
2. A_min / A_max
  - A：红绿通道
  - 范围：-128～127
  - 越小越绿，越大越红
3. B_min / B_max
  - B：蓝黄通道
  - 范围：-128～127
  - 越小越蓝，越大越黄

L管亮暗，A管红绿，B管蓝黄，每组都是「最小值到最大值」的筛选区间。

##### 二、可选过滤参数

###### 2. x_stride=2 / y_stride=1

- 扫描步长，越大识别越快、精度越低
- 如何理解步长？
  - 他的识别原理不是得几个几个像素扫描吗，就是跳了几个扫描呗
- 默认：x=2 y=1，一般不改

###### 3. invert=False

- False：找阈值内颜色（默认）
- True：反选，找阈值外的颜色
  - 就是把你画的范围外的都选上

###### 4. area_threshold=10

- 色块外接矩形面积下限，小于则过滤（不要了）
- 单位：像素
- 小目标改小，大目标改大

对象是具体图像上的画出的矩形

###### 5. pixels_threshold=10

- 色块实际像素点数下限，过滤噪点碎块
- 比 area_threshold 更精准过滤干扰

对象是直接的像素点数

###### 6. merge=False

- False：独立返回重叠/相近色块（默认）
- True：合并重叠/相邻色块，返回一个整体
- 核心：说白了就是是否合并重叠或者靠近的色块

###### 7. margin=0

- 合并的像素容差
- 仅 merge=True 生效，margin=5 表示间距≤5也合并
- 核心：说白了就是要离的多近才算要合并

###### 8. merge_func=None

- 自定义合并逻辑函数，高级用法，极少用

###### 三、返回值说明

返回色块对象列表，每个blob支持这些属性（任意变量都可以，这块是因为令blob = img.find_blobs了所以存储上的变量是blob）：

- blob.x() / blob.y()：左上角坐标
- blob.w() / blob.h()：宽高
- blob.pixels()：有效像素数
- blob.area()：外接矩形面积
- blob.cx() / blob.cy()：中心坐标
- blob.rotation()：旋转角度
- blob.code()：对应阈值索引（多颜色识别用）

###### 四、常用调用示例

1  # 追踪红色，合并色块，过滤小噪点
2  blobs = img.find_blobs(
3  thresholds=[(30, 100, 15, 127, 15, 127)],
4  pixels_threshold=200,
5  area_threshold=200,
6  merge=True,
7  margin=3
8  )

###### 五、快速记忆

- 必传：thresholds 阈值
- 滤噪点：pixels_threshold / area_threshold
- 合并色块：merge=True + margin
- 反色识别：invert=True

### 3. blob.w() / blob.h()

- 原型：blob.w() / blob.h()
- 作用：返回色块的像素宽度和高度。
- 底层逻辑：从 blob 对象中提取预计算好的几何特征值。

### 4. img.draw_rectangle()

- 原型：img.draw_rectangle(rect, color=127, thickness=1, fill=False)
- 参数：
  - rect：矩形坐标 (x, y, w, h)，这里直接用 blob.rect() 获取。
  - color：线条颜色（灰度图为 0-255）。
- 作用：在图像上画出包围色块的矩形框。

### 5. img.draw_string()

- 原型：img.draw_string(x, y, text, color=127, scale=1, mono_space=True)
- 参数：
  - x, y：字符串的左上角坐标。
  - text：要显示的文本，这里是计算出的距离。
- 作用：在图像上绘制文本，显示距离信息。

#### 具体参数说明：

img.draw_string() 是在图像上打印文字的函数，常用参数一共 6 个，其中前 4 个是核心必用/常用。

##### 完整参数格式

1  img.draw_string(x, y, text, color, scale, mono_space)

##### 逐个参数说明

1. x（必填）

文字左上角的 X 坐标

2. y（必填）

文字左上角的 Y 坐标

3. text（必填）

要显示的字符串/数字，必须加引号，数字用 str() 转

4. color（可选，默认白色）

文字颜色 (R, G, B)，例：(255,0,0) 红色

5. scale（可选，默认=1）

文字缩放倍数，2 就是两倍大，更清楚

6. mono_space（可选，默认=False）

是否等宽字符，一般不用改

##### 实战用法（和色块配合）

1  # 在色块左上角打印角度，红色，放大2倍
2  img.draw_string(blob.x(), blob.y(), f"Angle:{blob.rotation():.1f}",
3  color=(255,0,0), scale=2)

##### 极简记忆

必写：x, y, 文字内容

可选：颜色、大小、等宽

作用：把数据/提示画在画面上调试。

## 四、帧率计算

### 1. clock.tick()

- 原型：clock.tick()
- 作用：记录当前时间点，用于计算帧率。

### 2. clock.fps()

- 原型：clock.fps()
- 作用：返回从上次 tick() 到现在的平均帧率。

# （非）最终代码：

import sensor

import image #其实sensor已经隐式的引入了，但是还是留着吧

#import time

#核心参数

REAL_WID = 5.0 # 目标真实边长

FOCAL_LENGTH = 289 # 焦距（校过了）

BLACK_THRESH = (5, 20) # 黑色灰度阈值

MIN_AREA = 200 # 最小色块面积

WHITE_FIND = (230,255) #后有反选所以在找区块的时候要搞一个白的

#--摄像头初始化--

sensor.reset()

sensor.set_pixformat(sensor.GRAYSCALE) # 开灰度

sensor.set_framesize(sensor.QVGA)

#sensor.skip_frames(time=100) #跳过开头0.1秒

sensor.set_auto_gain(False) # 关闭自动增益，固定阈值生效

sensor.set_auto_whitebal(False) # 关闭白平衡

#clock = time.clock() 计算帧率可以加上

#---测距函数---

def get_distance(pixel_w):

"""相似三角形测距原理:

D = (真实 * 焦距) / 像素"""

if pixel_w < 1:

return 0.0

dist = (REAL_WID * FOCAL_LENGTH) / pixel_w

return round(dist, 2)

#---主循环---

while True:

#clock.tick()

img = sensor.snapshot() #取图像

img_binary = img.binary([BLACK_THRESH],invert = True) #灰度处理

img = img_binary #取了一个副本，用来存放，其实可以两个都显示，但是后面直接覆盖了

blobs = img.find_blobs([WHITE_FIND],area_threshold=MIN_AREA,invert = True,merge=True)

if blobs:

target = max(blobs, key=lambda b: b.area())

x, y, w, h = target.rect()

ratio = min(w, h) / max(w, h)#正方形长宽比为1，但是好像没啥用

if 0.8 < ratio < 1.2:

img.draw_rectangle((x, y, w, h), color=0)

distance = get_distance(w)

img.draw_string(x, y-12, f"{distance} cm", color=0, scale=1)

# 最终代码-连续检测图像输出

import sensor

import image #其实sensor已经隐式的引入了，但是还是留着吧

#import time

#核心参数

REAL_WID = 5.0 # 目标真实边长

FOCAL_LENGTH = 278 # 焦距（校过了）

BLACK_THRESH = (0, 10) # 黑色灰度阈值

MIN_AREA = 200 # 最小色块面积

WHITE_FIND = (230,255) #后有反选所以在找区块的时候要搞一个白的

#--摄像头初始化--

sensor.reset()

sensor.set_pixformat(sensor.GRAYSCALE) # 开灰度

sensor.set_framesize(sensor.QVGA)

#sensor.skip_frames(time=100) #跳过开头0.1秒

sensor.set_auto_gain(False) # 关闭自动增益，固定阈值生效

sensor.set_auto_whitebal(False) # 关闭白平衡

#clock = time.clock() 计算帧率可以加上

#---测距函数---

def get_distance(pixel_w):

"""相似三角形测距原理:

D = (真实 * 焦距) / 像素"""

if pixel_w < 1:

return 0.0

dist = (REAL_WID * FOCAL_LENGTH) / pixel_w

return round(dist, 2)

#---主循环---

while True:

#clock.tick()

img = sensor.snapshot() #取图像

img_binary = img.binary([BLACK_THRESH],invert = True) #灰度处理

img = img_binary #取了一个副本，用来存放，其实可以两个都显示，但是后面直接覆盖了

blobs = img.find_blobs([WHITE_FIND],area_threshold=MIN_AREA,invert = True,merge=True)

if blobs:

target = max(blobs, key=lambda b: b.area())

x, y, w, h = target.rect()

ratio = min(w, h) / max(w, h)#正方形长宽比为1，但是好像没啥用

if 0.8 < ratio < 1.2:

img.draw_rectangle((x, y, w, h), color=0)

distance = get_distance(w)

img.draw_string(x, y-12, f"{distance} cm", color=0, scale=1)

# 最终代码-检测5帧，输出一次平均值

import sensor

import image #其实sensor已经隐式的引入了，但是还是留着吧

import time

#---核心参数---

REAL_WID = 5.0 # 目标真实边长

FOCAL_LENGTH = 289 # 焦距（校过了）

BLACK_THRESH = (0, 10) # 黑色灰度阈值

MIN_AREA = 200 # 最小色块面积

WHITE_FIND = (230,255) #后有反选所以在找区块的时候要搞一个白的

SAMPLE_RAN = 5

INTER_TIME = 1

dis_list = []

#--摄像头初始化--

sensor.reset()

sensor.set_pixformat(sensor.GRAYSCALE) # 开灰度

sensor.set_framesize(sensor.QVGA)

sensor.skip_frames(time=500) #跳过开头0.1秒

sensor.set_auto_gain(False) # 关闭自动增益，固定阈值生效

sensor.set_auto_whitebal(False) # 关闭白平衡

#clock = time.clock() 计算帧率可以加上

#---测距函数---

def get_distance(pixel_w):

"""相似三角形测距原理:

D = (真实 * 焦距) / 像素"""

if pixel_w < 1:

return 0.0

dist = (REAL_WID * FOCAL_LENGTH) / pixel_w

return round(dist, 2)

#---单次测距函数---

def detect_once():

img = sensor.snapshot() #取图像

img_binary = img.binary([BLACK_THRESH], invert=True)#灰度处理

blobs = img_binary.find_blobs([WHITE_FIND], area_threshold=MIN_AREA, invert=True, merge=True)

if blobs:

target = max(blobs, key=lambda b: b.area())

x, y, w, h = target.rect()

ratio = min(w, h) / max(w, h)#正方形长宽比为1，但是好像没啥用

if 0.8 < ratio < 1.2:

return get_distance(w)

return 0.0

#---核心逻辑---

a = 1

for i in range(SAMPLE_RAN):

d = detect_once()

print

if d > 0: # 只加入有效距离

print(a,d)

a += 1

dis_list.append(d)

#time.sleep(INTER_TIME) # 采样间隔

#---计算并打印平均值---

if dis_list:

avg_dist = sum(dis_list) / len(dis_list)

print('avg dis is:')

print(round(avg_dist, 2)) # 只输出平均距离

else:

print('NONE') # 无有效检测

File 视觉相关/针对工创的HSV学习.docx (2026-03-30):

针对工创比赛的HSV入门学习

李铭萱整理

针对工创的HSV学习

# 图像HSV模型简介

HSV(Hue, Saturation, Value)是根据颜色的直观特性由A. R. Smith在1978年创建的一种颜色空间, 也称六角锥体模型(Hexcone Model)（参考百度）。

在HSV模型中，颜色是由色度（Hue），饱和度（Saturation），明度（Value）共同组成。

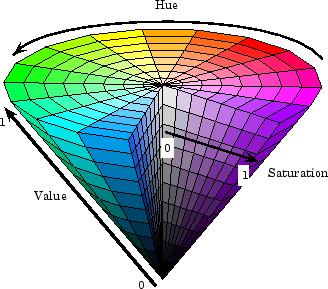
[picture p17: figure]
YA37ERBGADQFS
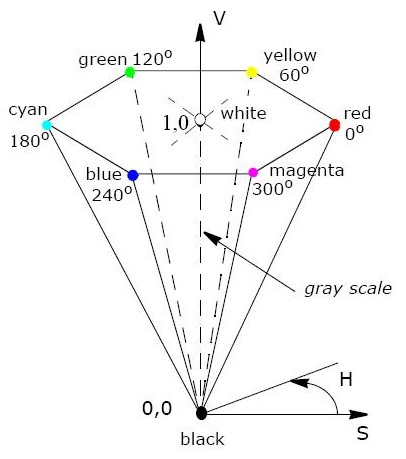
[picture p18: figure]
VXD66RBGABQGO

# HSV颜色空间介绍

## 一、HSV颜色空间的概念

HSV（Hue - Saturation - Value）是一种颜色模型，它将颜色描述为三个分量：

色调（Hue）：用于区分不同的颜色类别，取值范围通常为0 - 360°（在OpenCV中为0 - 179）。例如，红色大约在0°或180°，绿色在120°左右，蓝色在240°左右。它就像是颜色的“身份标识”，决定了我们看到的是红色、绿色还是其他颜色。

饱和度（Saturation）：表示颜色的纯度，取值范围是0 - 100%（在OpenCV等计算机视觉库中为0 - 255）。饱和度越高，颜色越鲜艳；当饱和度为0时，颜色变为灰度，即没有颜色成分，只有亮度信息。

明度（Value）：描述颜色的明亮程度，取值范围也是0 - 100%（在计算机视觉库中为0 - 255）。明度为0时表示黑色，明度越高，颜色越亮。

如图所示，HSV模型中

## 色度（Hue）

使用角度度量的，范围是从0 ° 到360 ° （逆时针旋转），比如0 ° / 360 ° 代表红色，120 ° 代表绿色，240 °代表蓝色。

## 饱和度（Saturation）

表示颜色接近光谱色的程度。一种颜色，可以看成是某种光谱色与白色混合的结果。其中光谱色所占的比例愈大，颜色接近光谱色的程度就愈高，颜色的饱和度也就愈高（参考百度）。其范围是0到1。

## 明度（Value）

颜色明亮的程度，对于光源色，明度值与发光体的光亮度有关。其范围是0（暗）到1（明）。

# RGB转HSV公式

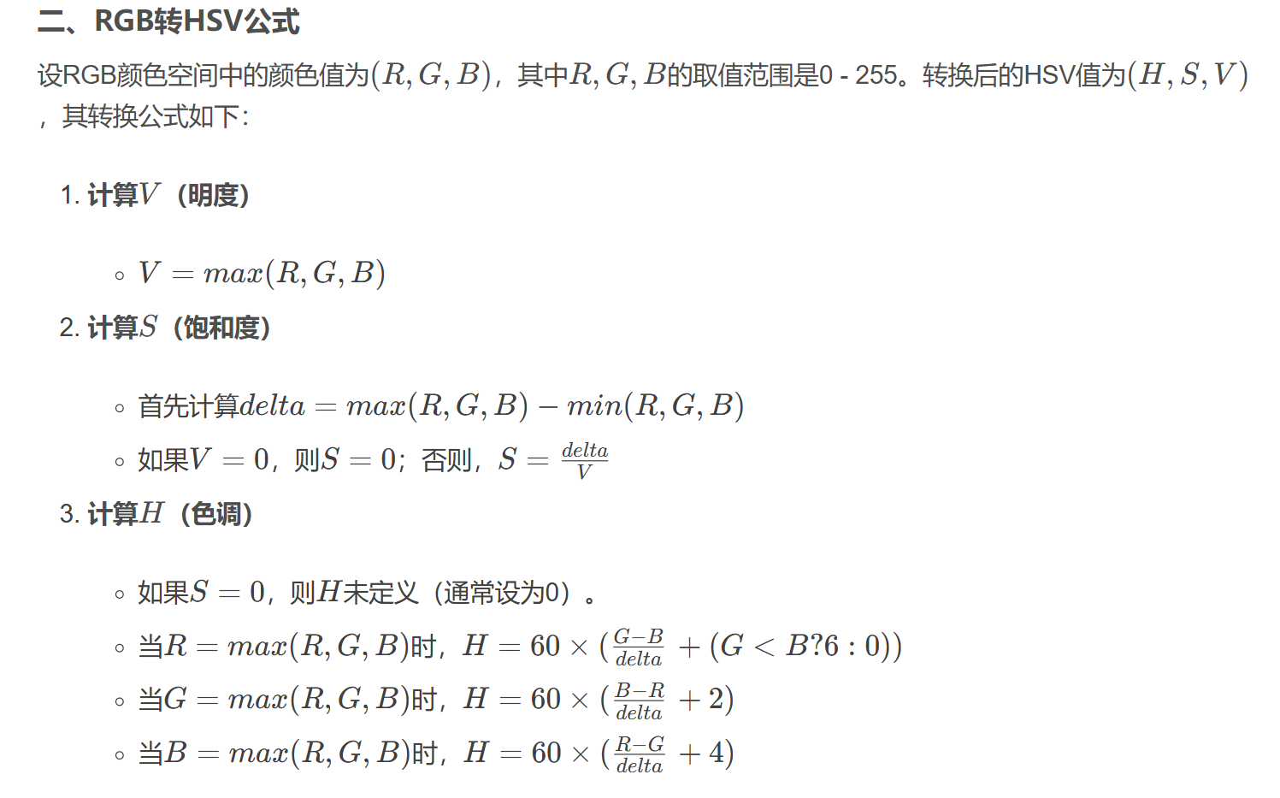
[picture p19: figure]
X3QPORBGABAHM

# opencv关于HSV模型实验

使用opencv将RGB模型图像转成HSV模型图像非常简单，直接使用cv2.cvtColor函数，在code参数中传入cv2.COLOR_RGB2HSV参数即可。 但需要注意一下，通过opencv转HSV后会根据传入的数据类型缩放到不同范围，如果输入的是Uint8类型的数据（一般读入的图片数据类型都是Uint8），默认缩放到0到255之间 。 那么对于饱和度和明度（默认0到1之间）而言直接乘以255然后取整即可。对于色度（默认是在0到360之间）由于超出了Uint8数据类型的范围，所以官方储存时是直接除以2即缩放到0到180之间。参考opencv官方文档：https://docs.opencv.org/master/de/d25/imgproc_color_conversions.html#color_convert_rgb_hsv

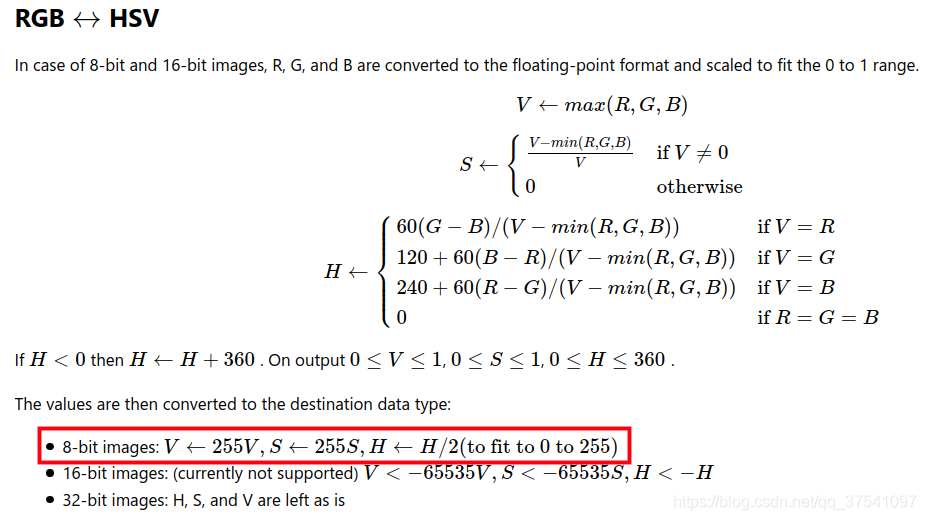
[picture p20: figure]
PWSAARJGABQHM

那么对于刚刚讲的示例将（110， 20， 50）RGB模型空间转到HSV模型空间得到是（340，0.8183，0.4314），按照刚刚讲的在opencv转换后应该是：

H:340/2⟶170

S:0.8183×255⟶209

V:0.4314×255⟶110

使用opencv转换试下看对不对：

1  import cv2
2  import numpy as np
4  rgb = np.array([110, 20, 50], dtype=np.uint8).reshape((1, 1, 3))
5  hsv = cv2.cvtColor(rgb, cv2.COLOR_RGB2HSV)
6  print(hsv)

终端打印的结果是[170 209 110]，和我们计算的是一样的，说明理解到位。

接下来在使用opencv来固定色度，饱和度，明度其中两个变量，渐变剩下一个变量来看看效果。

# HUE色度渐变实验

固定sat（饱和度）以及val（明度），渐变hue（色度）。从左到右数值从0到180（对应hue中0 ° 到360 ° ）

1  import cv2
2  import numpy as np
5  hue = np.tile(np.arange(0, 180, dtype=np.uint8).reshape((1, 180, 1)),
6  (50, 1, 1))
7  sat= np.ones((50, 180, 1), dtype=np.uint8) * 255
8  val = np.ones((50, 180, 1), dtype=np.uint8) * 255
9  img_hsv = cv2.merge((hue, sat, val))
10  img = cv2.cvtColor(img_hsv, cv2.COLOR_HSV2BGR)
11  # img = cv2.resize(img, (720, 100))
12  cv2.imshow("img", img)
13  cv2.waitKey(0)

结果：

# SAT饱和度渐变实验

固定hue（色度）以及val（明度），渐变sat（饱和度）。从左到右数值从0到255（对应sat中0到1，饱和度越来越高）

1  import cv2
2  import numpy as np
5  hue = np.zeros((100, 256, 1), dtype=np.uint8)
6  sat = np.tile(np.arange(0, 256, dtype=np.uint8).reshape((1, 256, 1)),
7  (100, 1, 1))
8  val = np.ones((100, 256, 1), dtype=np.uint8) * 255
9  img_hsv = cv2.merge((hue, sat, val))
10  img = cv2.cvtColor(img_hsv, cv2.COLOR_HSV2BGR)
11  # img = cv2.resize(img, (720, 100))
12  cv2.imshow("img", img)
13  cv2.waitKey(0)

结果：

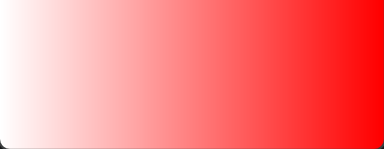
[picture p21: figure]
4VEAWRJGABAHM

# VAL明度渐变实验

固定hue（色度）以及sat（饱和度），渐变val（明度）。从左到右数值从0到255（对应val中0到1，明度越来越高）

1  import cv2
2  import numpy as np
5  hue = np.zeros((100, 256, 1), dtype=np.uint8)
6  sat = np.ones((100, 256, 1), dtype=np.uint8) * 255
7  val = np.tile(np.arange(0, 256, dtype=np.uint8).reshape((1, 256, 1)),
8  (100, 1, 1))
9  img_hsv = cv2.merge((hue, sat, val))
10  img = cv2.cvtColor(img_hsv, cv2.COLOR_HSV2BGR)
11  # img = cv2.resize(img, (720, 100))
12  cv2.imshow("img", img)
13  cv2.waitKey(0)

结果：

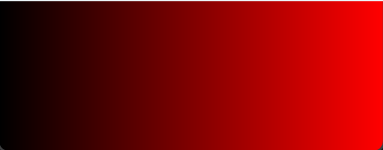
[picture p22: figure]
FMMAYRJGADAHU

# 其余示例代码

1  import cv2
2  import numpy as np
4  # 读取图像
5  image = cv2.imread('your_image.jpg')
6  # 将图像从BGR转换为HSV
7  hsv_image = cv2.cvtColor(image, cv2.COLOR_BGR2HSV)
9  # 定义要提取颜色的HSV范围（以提取蓝色为例）
10  lower_blue = np.array([100, 50, 50])
11  upper_blue = np.array([140, 255, 255])
13  # 创建掩码
14  mask = cv2.inRange(hsv_image, lower_blue, upper_blue)
16  # 对原图像和掩码进行位运算，提取蓝色物体
17  result = cv2.bitwise_and(image, image, mask = mask)
19  # 显示结果
20  cv2.imshow('Original Image', image)
21  cv2.imshow('Mask', mask)
22  cv2.imshow('Result', result)
23  cv2.waitKey(0)
24  cv2.destroyAllWindows()

## 代码逻辑：

在上述示例中：首先通过cv2.imread()函数读取一张图像，然后使用cv2.cvtColor()函数将其从BGR颜色空间转换为HSV颜色空间。这是因为cv2.inRange()函数在HSV空间中进行颜色范围提取更加方便直观。

接着定义了要提取的蓝色在HSV空间中的范围。lower_blue和upper_blue分别是下限和上限阈值数组，这里的数值是根据蓝色在HSV空间中的大致范围确定的。

使用cv2.inRange()函数创建了一个掩码。这个掩码中只有蓝色物体对应的像素位置为255，其他位置为0。

最后，通过cv2.bitwise_and()函数将原图像和掩码进行位运算，得到只包含蓝色物体的图像。并通过cv2.imshow()函数显示了原始图像、掩码和最终结果，cv2.waitKey(0)等待用户按键，cv2.destroyAllWindows()关闭所有打开的窗口。

请注意，在实际应用中，你需要将your_image.jpg替换为你自己的图像路径。同时，颜色范围的设定可能需要根据具体的图像和提取目标进行调整。

# 适配 OPENMV 做颜色筛选的补充内容

OPENMV 的 HSV 规则和 OpenCV有细微差异，且实际工程应用中需要考虑鲁棒性，以下是针对 “筛选红 / 绿 / 蓝三种物块” 的关键补充：

## 1. OPENMV 与 OpenCV 的 HSV 范围差异（核心！）

表格

分量 | OpenCV 范围 | OPENMV 范围 | 转换关系
色调 H | 0-179 | 0-359 | OPENMV_H = OpenCV_H × 2
饱和度 S | 0-255 | 0-100 | OPENMV_S = OpenCV_S × 100/255
明度 V | 0-255 | 0-100 | OPENMV_V = OpenCV_V × 100/255

比如你在 OpenCV 中定义的蓝色范围[100,50,50]~[140,255,255]，对应 OPENMV 的范围是：

- H：200 ~ 280
- S：20 ~ 100
- V：20 ~ 100

## 2. OPENMV 颜色筛选的实战代码

以下是可直接在 OPENMV 上运行的颜色筛选代码，适配红 / 绿 / 蓝三种颜色，注释清晰：

1  import sensor, image, time
3  # 初始化摄像头
4  sensor.reset()
5  sensor.set_pixformat(sensor.RGB565) # 图像格式，RGB565足够满足颜色识别
6  sensor.set_framesize(sensor.QVGA) # 分辨率QVGA(320x240)，兼顾速度和精度
7  sensor.skip_frames(time=2000) # 跳过初始帧，让摄像头稳定
8  sensor.set_auto_gain(False) # 关闭自动增益（关键！否则颜色会飘）
9  sensor.set_auto_whitebal(False) # 关闭自动白平衡（关键！否则颜色会飘）
10  clock = time.clock()
12  # 定义三种颜色的HSV范围（OPENMV格式）
13  # 注意：红色的H范围是0-10 和 350-360（因为红色在HSV环上是首尾相连的）
14  color_ranges = {
15  "red": [(0, 20, 20), (10, 100, 100), (350, 20, 20), (360, 100, 100)],
16  "green": [(60, 20, 20), (120, 100, 100)],
17  "blue": [(200, 20, 20), (280, 100, 100)]
18  }
20  # 选择要识别的颜色（修改这里切换目标颜色）
21  target_color = "blue"
23  def detect_color(img, target_range):
24  """
25  颜色筛选核心函数：返回只保留目标颜色的二值图像
26  """
27  # 创建掩码（初始全黑）
28  mask = img.new_image(img.width(), img.height(), sensor.GRAYSCALE)
29  mask.clear()
31  # 遍历颜色范围（红色需要处理两个区间）
32  for i in range(0, len(target_range), 2):
33  lower = target_range[i]
34  upper = target_range[i+1]
35  # 在HSV空间中筛选颜色，结果合并到掩码中
36  img.binary([(lower[0], upper[0], lower[1], upper[1], lower[2], upper[2])],
37  invert=False, mask=mask)
38  return mask
40  # 主循环
41  while True:
42  clock.tick()
43  img = sensor.snapshot()
45  # 筛选目标颜色
46  color_mask = detect_color(img, color_ranges[target_color])
48  # 将掩码叠加到原图（方便可视化，只显示目标颜色）
49  img.apply_mask(color_mask, alpha=128) # alpha是透明度，128表示半透明叠加
51  # 可选：查找颜色区域的轮廓（定位物块）
52  blobs = img.find_blobs([color_ranges[target_color][0], color_ranges[target_color][1]],
53  pixels_threshold=200, area_threshold=200)
54  for b in blobs:
55  img.draw_rectangle(b.rect(), color=(255,0,0)) # 画矩形框出物块
56  img.draw_cross(b.cx(), b.cy(), color=(0,255,0)) # 画十字标中心
58  print(f"FPS: {clock.fps()}") # 打印帧率，监控性能

## 3. 工程应用的关键补充点

1. 环境光校准：

实际场景中光线变化会影响颜色识别，建议在开机时采集一次背景色，或者手动调整 HSV 范围（可以做一个串口调试界面，实时修改 H/S/V 的上下限）。

OPENMV 可以通过sensor.set_brightness()/sensor.set_contrast()微调图像参数，适配不同光线。

2. 红色的特殊处理：

红色的 H 值在 HSV 环上是 “首尾相连” 的（0° 和 360° 都是红色），所以 OPENMV 中需要同时处理0-10和350-360两个区间（代码中已体现），否则会漏检。

3. 鲁棒性优化：

用find_blobs时，设置pixels_threshold（最小像素数）和area_threshold（最小面积），过滤掉小的噪声点。

  - 可以对掩码做形态学操作（膨胀 / 腐蚀），比如color_mask.erode(1)/color_mask.dilate(1)，消除噪点

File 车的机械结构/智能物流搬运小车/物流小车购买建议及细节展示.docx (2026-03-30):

云台

【淘宝】7天无理由退货 http://e.tb.cn/h.TWmCarq8xqTDpeU?tk=Jiaq3vTVkcE CA6496 「一二维电动舵机云台转台机械臂一自由度云台配件支架360°度转动」

点击链接直接打开 或者 淘宝搜索直接打开

（买大云台，舵机自选，别买360度舵机就行）

导轨，滑块

【淘宝】退货运费险 http://e.tb.cn/h.TW9DdwS6Ym0EmNn?tk=QWAS3vTTfTi MF7997 「国产上银微型直线导轨滑块滑轨MGN/MGW/7C/9C/12C/15C/7H/12H/15H」

点击链接直接打开 或者 淘宝搜索直接打开

（MGN7 280mm,滑块也是MGN7C，这个可以自由选择也可以买更宽一点的导轨滑块，孔位就要自己改一下了，买别的家的也可以我只是提供一个样板，这个导轨别的家也有）

L型导轨支架

【淘宝】假一赔四 http://e.tb.cn/h.TWnvngLMIq7eNaa?tk=FYnB3vhXB9N MF1643 「不锈钢角码长孔可调节直角90度固定器一字l型直片活动角铁连接件」

点击链接直接打开 或者 淘宝搜索直接打开

（用成品支架强度好，不会弯，我们用的这个L型支架强度很好，但是孔位有点对不上，解决方式是加了很大的垫片（如下图）这样实际效果就很好了，这里只是列举这个方案，大家可以按需改善）

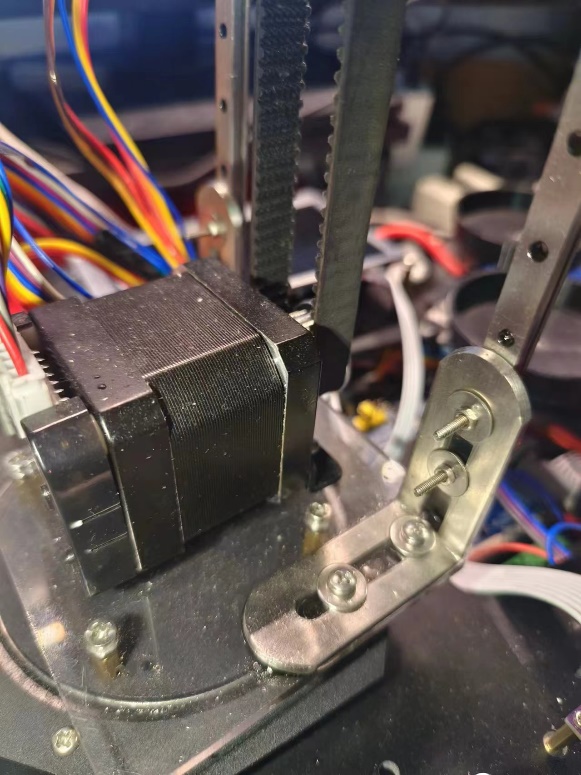
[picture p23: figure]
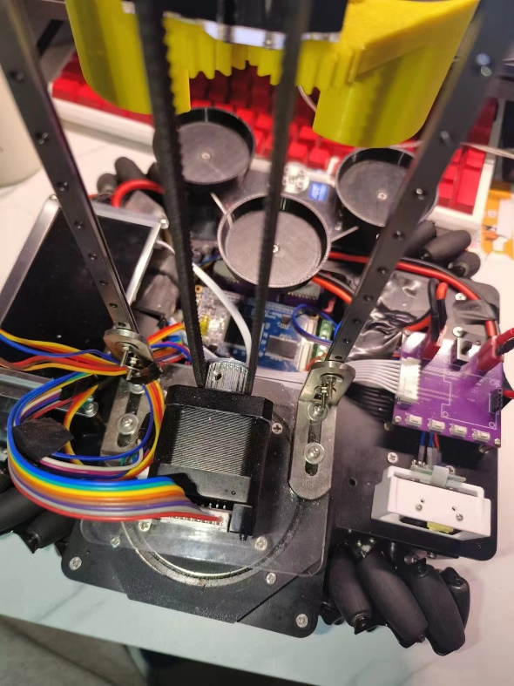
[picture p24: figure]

带轮和皮带

带轮上：

【淘宝】7天无理由退货 http://e.tb.cn/h.TWPxl2TL0gdiuVQ?tk=i1XE3vhf3j9 CZ0015 「带轴承同步轮 3M20齿 内孔3/4/5/6 涨紧轮 调节导向轮 惰轮 带轮」

点击链接直接打开 或者 淘宝搜索直接打开

带轮下：

【淘宝】7天无理由退货 http://e.tb.cn/h.TWPCl7x44JcHhYI?tk=NqtQ3vh5d13 HU0854 「3M20齿两面平同步轮AF同步带轮齿宽11/16齿外径18.33皮带轮传动轮」

点击链接直接打开 或者 淘宝搜索直接打开

皮带：

【淘宝】7天无理由退货 http://e.tb.cn/h.TWPxEIu4OHyaoeQ?tk=SoPu3vh5NEw MF7997 「橡胶同步带 3M558/561/564/567/570/573/576/579/582/585/588/591」

点击链接直接打开 或者 淘宝搜索直接打开


(带轮上用有轴承的，这样会更加丝滑，我这里的一套是3m的，我们皮带长度560大家根据实际情况选择)

42步进电机支架

小支架：

【淘宝】7天无理由退货 http://e.tb.cn/h.TWM2VlRnxRnrv4V?tk=MnQc3vhjmA1 CZ8908 「3D打印机Z轴专用电机支架 丝杆42步进电机固定件 42电机安装支架」

点击链接直接打开 或者 淘宝搜索直接打开


（这个小支架可以放在云台上给42步进电机使用，这个支架优点就是小巧省空间，不一定买这家哈，只是举例。下面4个麦轮的42步进电机网上随便买）

麦轮

【淘宝】7天无理由退货 http://e.tb.cn/h.TWl8ktSuq1hIvWi?tk=HerP3vhtlME HU7632 「一组4个3英寸天府之土麦克纳姆 轮含联轴器290元智能车机器人底盘」

点击链接直接打开 或者 淘宝搜索直接打开

（这个麦轮稍稍有点贵但是好很多做工很好，实际比赛很多人都用他们家的麦轮，我们组也是，大家也可以按需购买，能连上42步进电机的5mm轴就行）

其他零件如一些板材，3d打印件之类的大家按需选择材料加工即可，铜柱及螺栓螺母垫片等按需购买即可，顶部的带轮固定片做了一些可调节的设计（如下图），上面那个有轴承的带轮中间的轴是一根5mm钢柱，网上可以买，两头螺栓固定

【淘宝】7天无理由退货 http://e.tb.cn/h.T377U1hBGIlcolv?tk=SxzP3vSYXcR HU9196 「304不锈钢双头内螺纹圆柱销两头带孔支撑柱连接杆M3M4M5M6M8M10」

点击链接直接打开 或者 淘宝搜索直接打开


附加一些细节图片



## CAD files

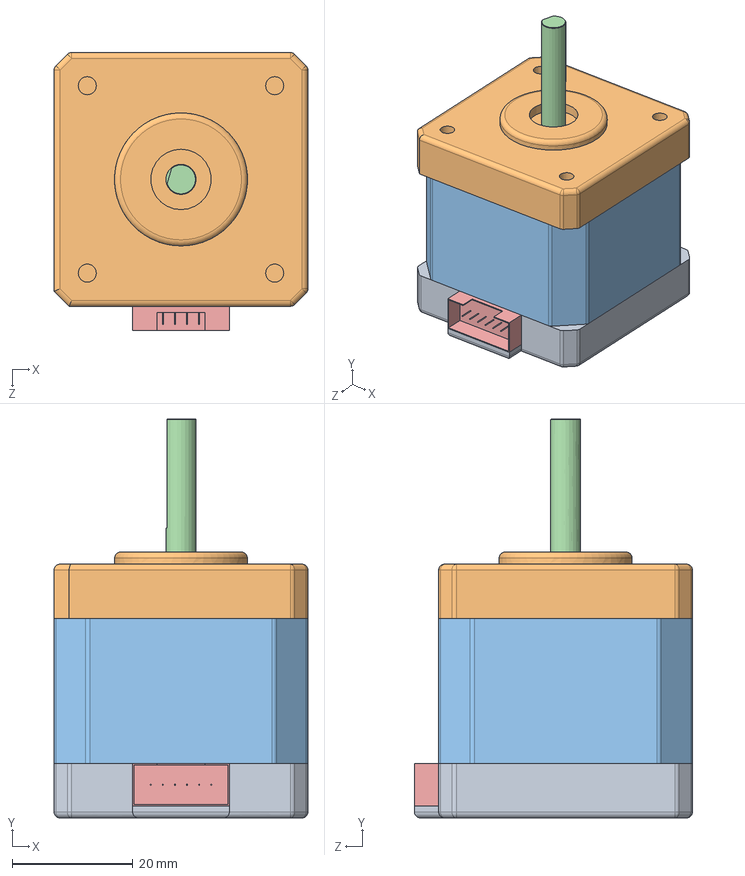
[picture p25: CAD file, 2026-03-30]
车的机械结构/智能物流搬运小车/升降机构/42步进电机/42步进电机.SLDASM
42.0 x 66.0 x 46.0 mm
42步进电机-01
42步进电机-02
42步进电机-03
42步进电机-04
42步进电机-05

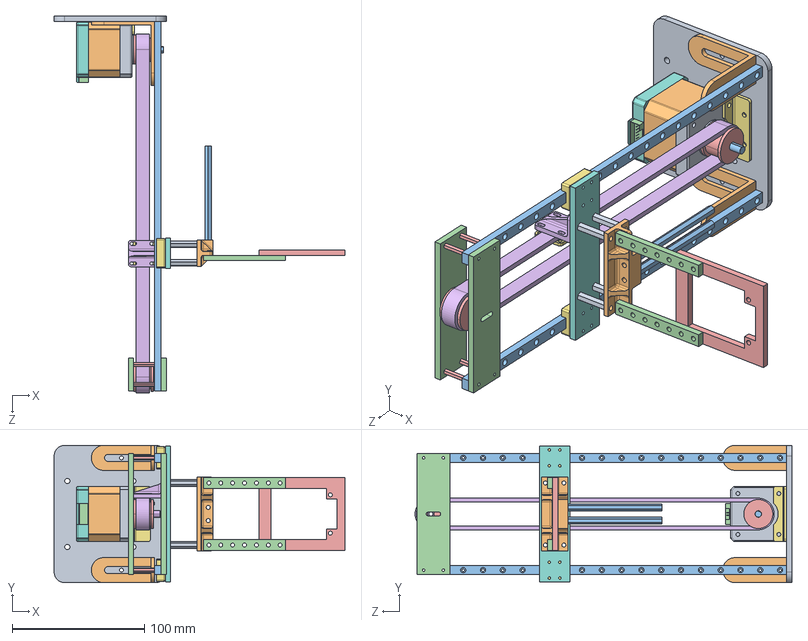
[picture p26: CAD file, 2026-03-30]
车的机械结构/智能物流搬运小车step/升降机构/1升降机构装配.step
220.2 x 104.0 x 285.5 mm
升降底座
滑轨L支架 x 2
280mm导轨 x 2
滑轨顶部片 x 2
16mm铜柱（m2） x 4
20mm钢柱(m3)
42步进电机支架(小)
42步进电机-01
42步进电机-02
42步进电机-03
42步进电机-04
42步进电机-05
带轮 x 2
皮带
滑块 x 2
滑块片
20mm铜柱（m3） x 4
80铜柱爪子支架
80mm铜柱(m3) x 2
摄像头延长 x 2
摄像头支架
皮带固定片1
皮带固定片2

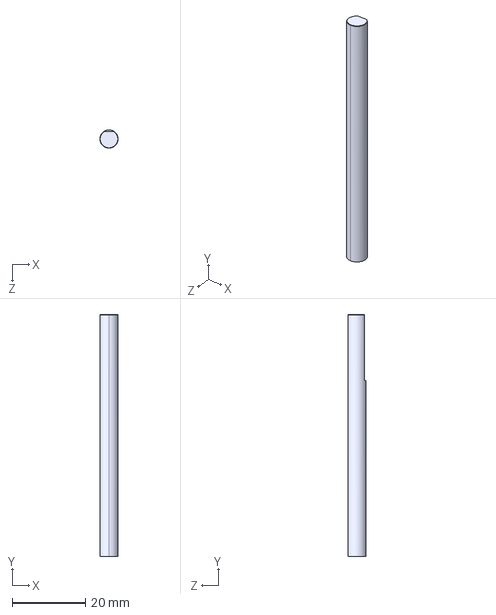
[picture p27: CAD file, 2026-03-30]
车的机械结构/智能物流搬运小车step/升降机构/42步进电机/42步进电机-04.step
5.00 x 66.0 x 5.00 mm

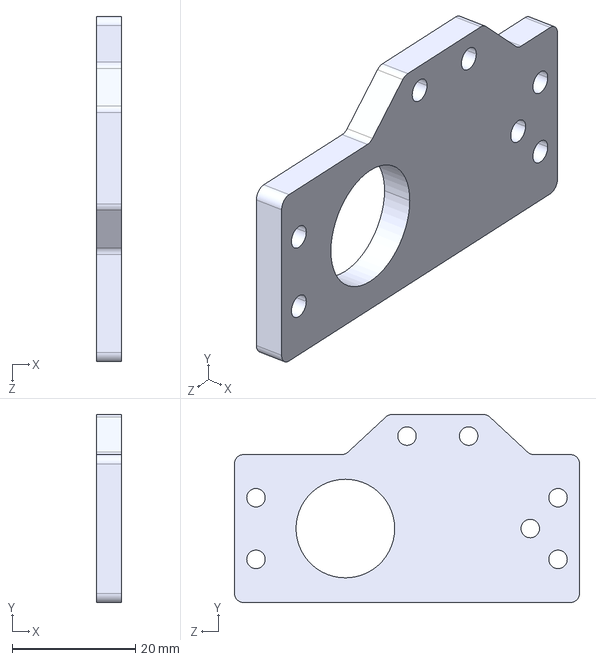
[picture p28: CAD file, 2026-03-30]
车的机械结构/智能物流搬运小车step/爪子/舵机爪子夹片正.step
4.00 x 30.5 x 56.0 mm

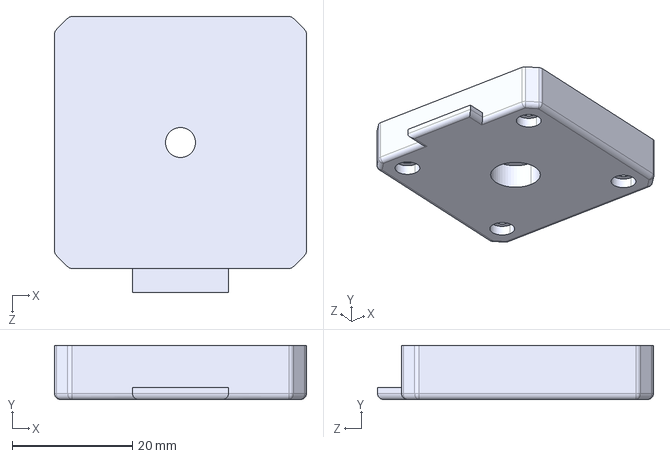
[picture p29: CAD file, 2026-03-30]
车的机械结构/智能物流搬运小车step/车身/42步进电机/42步进电机-01.step
42.0 x 9.00 x 46.0 mm

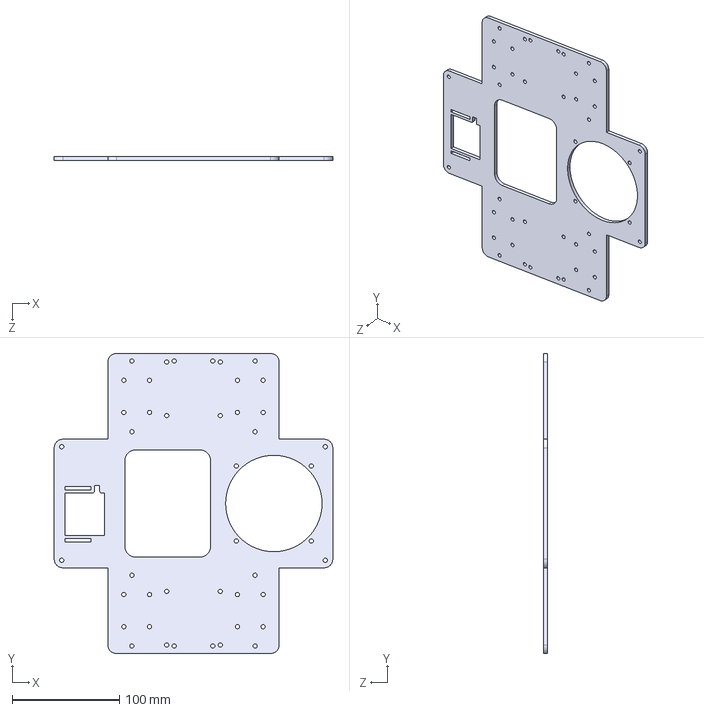
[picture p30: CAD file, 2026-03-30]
车的机械结构/智能物流搬运小车step/车身/小车底盘上.step
260.0 x 280.0 x 4.00 mm

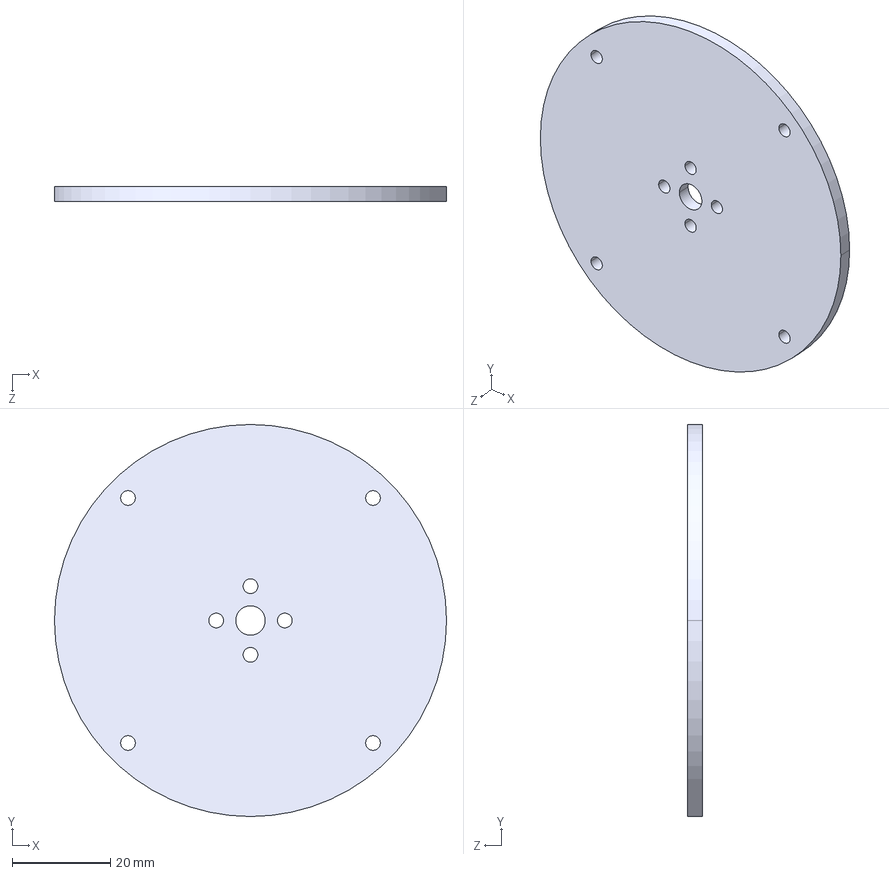
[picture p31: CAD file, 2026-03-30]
车的机械结构/智能物流搬运小车step/云台/轴承夹片（小下）.step
80.0 x 80.0 x 3.00 mm

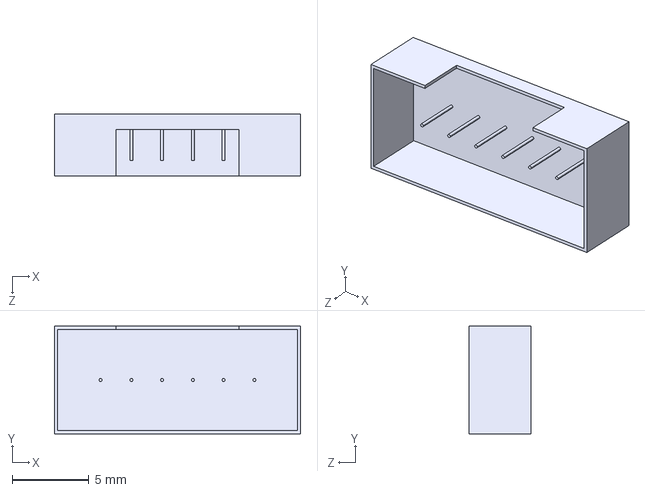
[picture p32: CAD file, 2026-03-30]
车的机械结构/智能物流搬运小车step/升降机构/42步进电机/42步进电机-05.step
16.0 x 7.00 x 4.00 mm

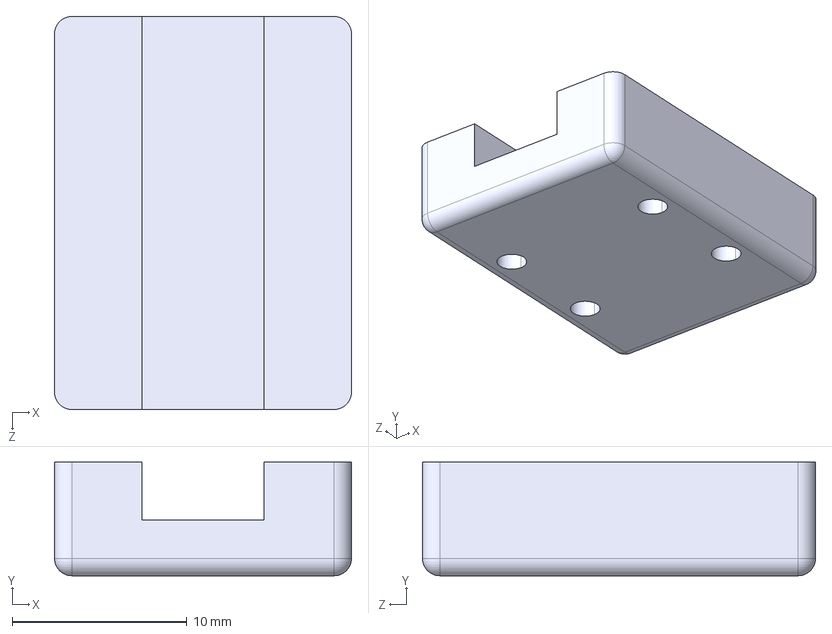
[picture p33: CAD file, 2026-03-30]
车的机械结构/智能物流搬运小车step/升降机构/滑块.step
17.0 x 6.50 x 22.5 mm

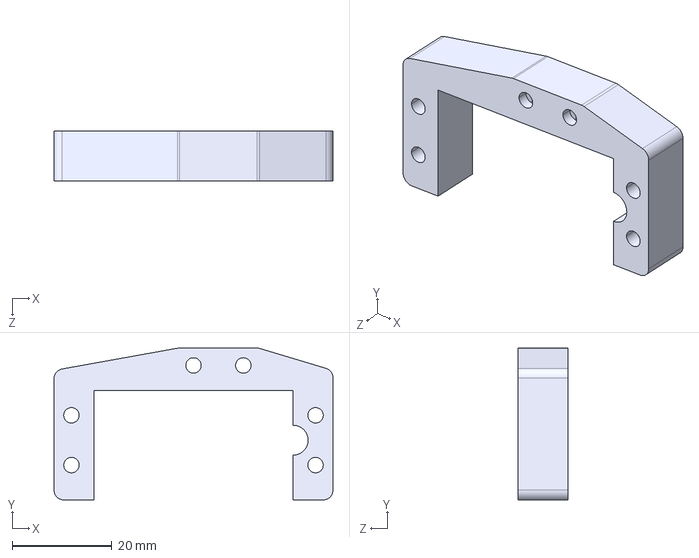
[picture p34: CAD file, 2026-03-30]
车的机械结构/智能物流搬运小车step/爪子/夹爪的舵机夹片.step
56.0 x 30.5 x 10.0 mm

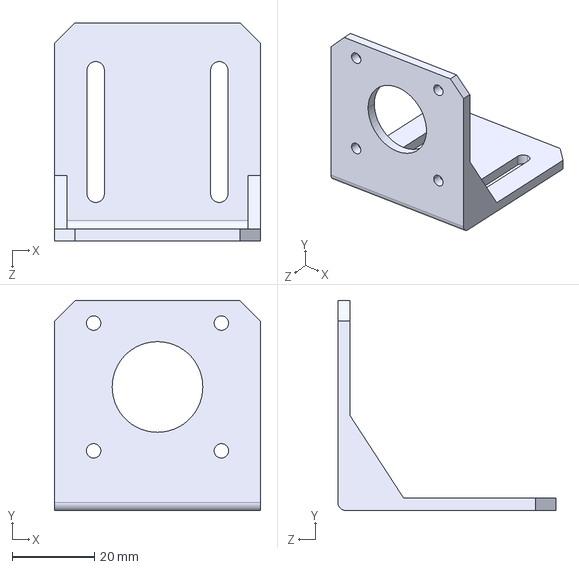
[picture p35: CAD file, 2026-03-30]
车的机械结构/智能物流搬运小车step/车身/42步进电机支架.step
50.0 x 51.0 x 53.0 mm

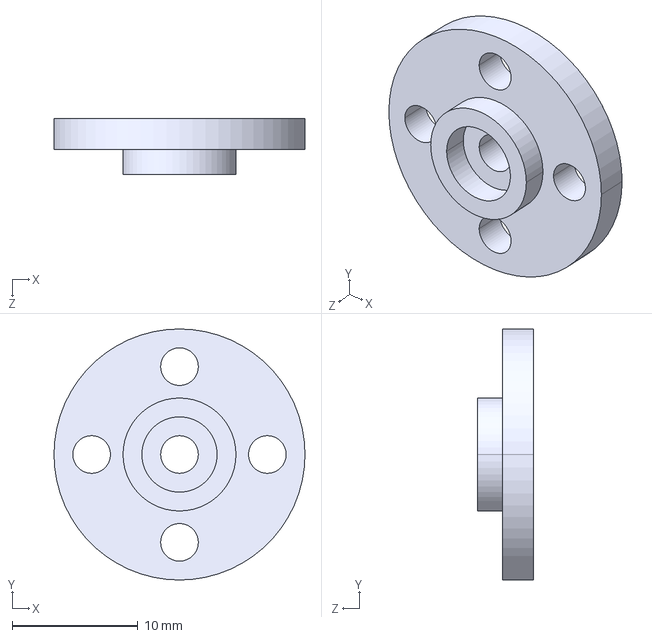
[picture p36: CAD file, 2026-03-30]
车的机械结构/智能物流搬运小车step/转盘/金属舵盘.step
20.0 x 20.0 x 4.50 mm

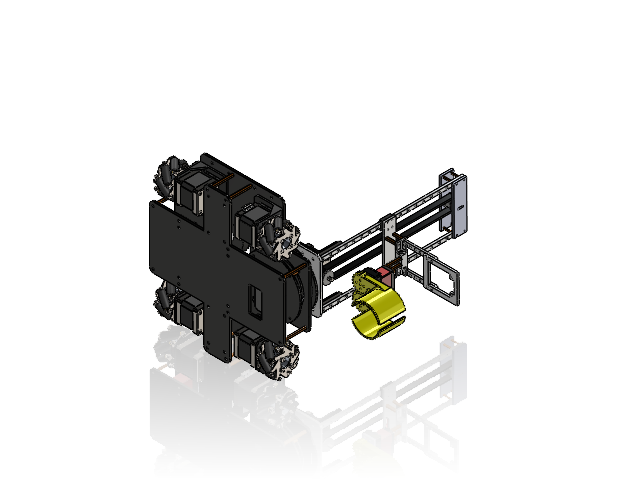
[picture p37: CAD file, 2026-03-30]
车的机械结构/智能物流搬运小车/总装配体/智能物流搬运小车.SLDASM
小车底盘上
小车底盘下
42步进电机支架 x 4
42步进电机-01 x 5
42步进电机-02 x 5
42步进电机-03 x 5
42步进电机-04 x 5
42步进电机-05 x 5
45mm铜柱(m3) x 8
麦轮 x 4
二维码支架
轴承
轴承夹片（大）
轴承夹片（小上）
轴承夹片（小下）
舵机夹片
金属舵盘 x 3
舵机（大） x 3
10mm铜柱 x 8
转盘
物料槽 x 3
升降底座
滑轨L支架 x 2
280mm导轨 x 2
滑轨顶部片 x 2
16mm铜柱（m2） x 4
20mm钢柱(m3)
42步进电机支架(小)
带轮 x 2
皮带
滑块 x 2
滑块片
20mm铜柱（m3） x 4
80铜柱爪子支架
80mm铜柱(m3) x 2
摄像头延长 x 2
摄像头支架
皮带固定片1
皮带固定片2
夹爪的舵机夹片
上爪
下爪
舵机爪子夹片正

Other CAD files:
车的机械结构/智能物流搬运小车step/云台/金属舵盘.step
车的机械结构/智能物流搬运小车/云台/10mm铜柱.SLDPRT
车的机械结构/智能物流搬运小车/云台/1云台装配.SLDASM
车的机械结构/智能物流搬运小车/云台/舵机夹片.SLDPRT
车的机械结构/智能物流搬运小车/云台/舵机（大）.SLDPRT
车的机械结构/智能物流搬运小车/云台/轴承.SLDPRT
车的机械结构/智能物流搬运小车/云台/轴承夹片（大）.SLDPRT
车的机械结构/智能物流搬运小车/云台/轴承夹片（小上）.SLDPRT
车的机械结构/智能物流搬运小车/云台/轴承夹片（小下）.SLDPRT
车的机械结构/智能物流搬运小车/云台/金属舵盘.SLDPRT
车的机械结构/智能物流搬运小车/升降机构/16mm铜柱（m2）.SLDPRT
车的机械结构/智能物流搬运小车/升降机构/1升降机构装配.SLDASM
车的机械结构/智能物流搬运小车/升降机构/20mm钢柱(m3).SLDPRT
车的机械结构/智能物流搬运小车/升降机构/20mm铜柱（m3）.SLDPRT
车的机械结构/智能物流搬运小车/升降机构/280mm导轨.SLDPRT
车的机械结构/智能物流搬运小车/升降机构/42步进电机/42步进电机-01.SLDPRT
车的机械结构/智能物流搬运小车/升降机构/42步进电机/42步进电机-02.SLDPRT
车的机械结构/智能物流搬运小车/升降机构/42步进电机/42步进电机-03.SLDPRT
车的机械结构/智能物流搬运小车/升降机构/42步进电机/42步进电机-04.SLDPRT
车的机械结构/智能物流搬运小车/升降机构/42步进电机/42步进电机-05.SLDPRT
车的机械结构/智能物流搬运小车/升降机构/42步进电机支架(小).SLDPRT
车的机械结构/智能物流搬运小车/升降机构/80mm铜柱(m3).SLDPRT
车的机械结构/智能物流搬运小车/升降机构/80铜柱爪子支架.SLDPRT
车的机械结构/智能物流搬运小车/升降机构/升降底座.SLDPRT
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

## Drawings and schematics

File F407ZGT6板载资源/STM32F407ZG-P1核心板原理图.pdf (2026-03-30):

VDD_1 72 PB12 73 PB13 74 PB14 75 PB15 76 PD8 77 PD9 78 PD10 79 PD11 80 PD12 81 PD13 82 VSS_8 83 VDD_8 84 PD14 85 PD15 86 PG2 87 PG3 88 PG4 89 PG5 90 PG6 91 PG7 92 PG8 93 VSS_9 94 VDD_9 95 PC6 96 PC7 97 PC8 98 PC9 99 PA8 100 PA9 101 PA10 102 PA11 103 PA12 104 PA13 105 NC 106 VSS_2 107 VDD_2 108 PA14 109 PA15 110 PC10 111 PC11 112 PC12 113 PD0 114 PD1 115 PD2 116 PD3 117 PD4 118 PD5 119 VSS_10 120 VDD_10 121 PD6 122 PD7 123 PG9 124 PG10 125 PG11 126 PG12 127 PG13 128 PG14 129 VSS_11 130 VDD_11 131 PG15 132 PB3 133 PB4 134 PB5 135 PB6 136 PB7 137 BOOT0 138 PB8 139 PB9 140 PE0 141 PE1 142 VSS_3 143 VDD_3 144

# RTC时钟晶振

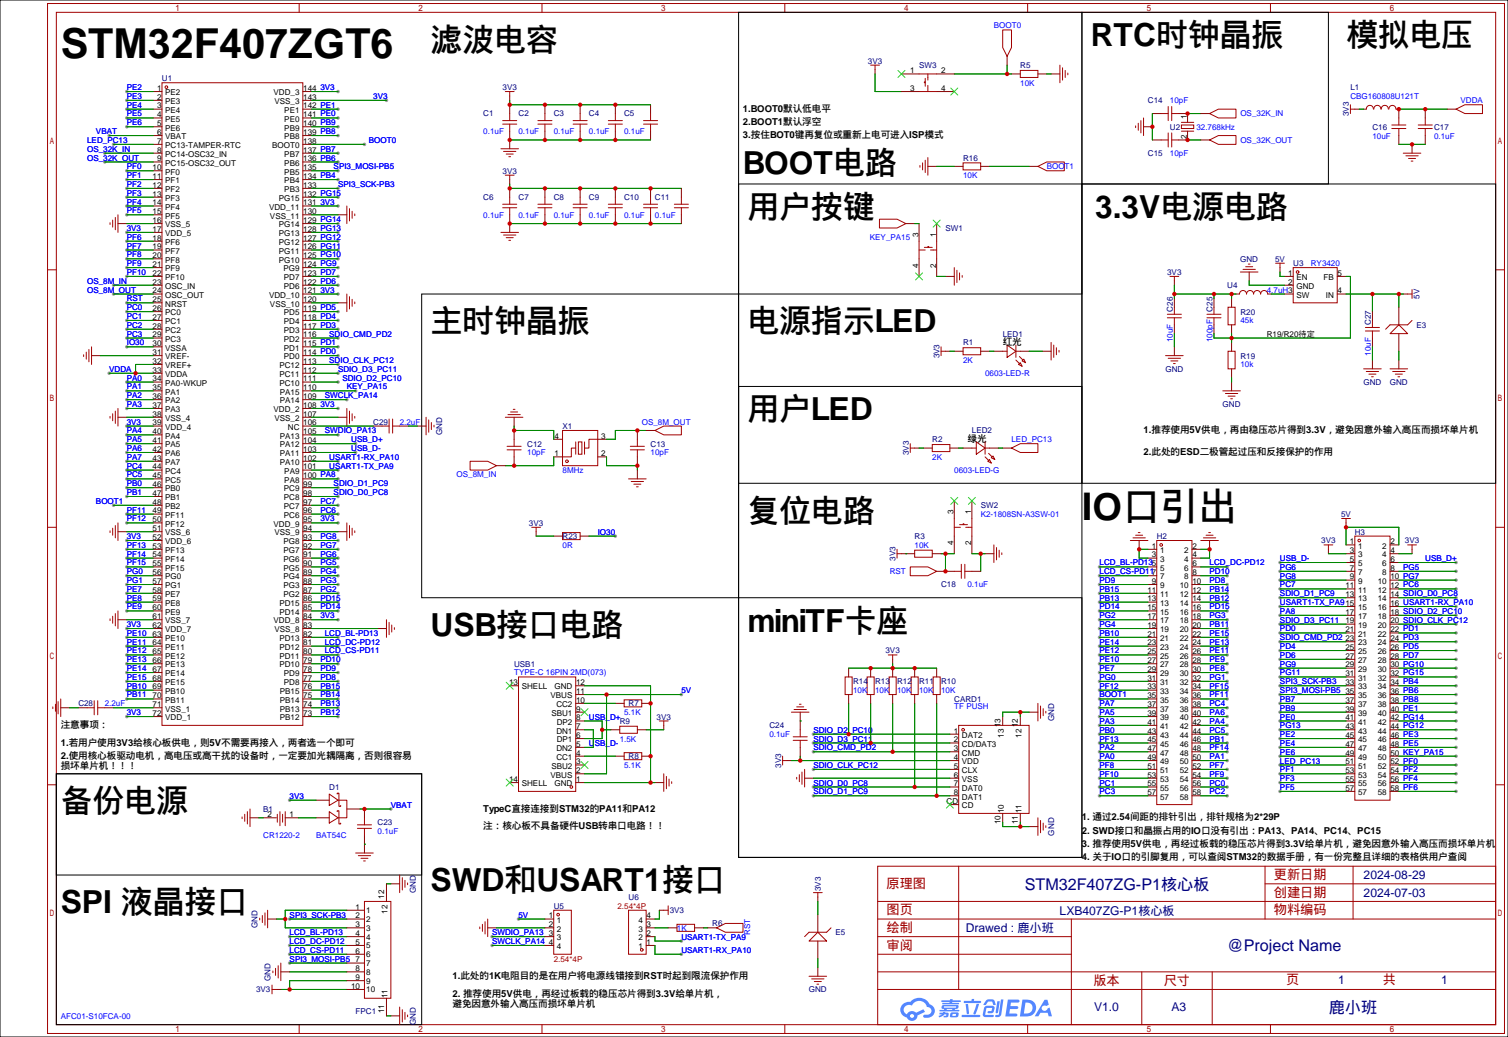
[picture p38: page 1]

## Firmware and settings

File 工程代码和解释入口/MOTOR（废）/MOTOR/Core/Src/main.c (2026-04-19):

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
/* Includes ------------------------------------------------------------------*/
#include "main.h"
#include "usart.h"
#include "gpio.h"

/* USER CODE BEGIN Includes */
#include <stdbool.h>
/* USER CODE END Includes */

/* USER CODE BEGIN PTD */
	#define SHARED_EN_PORT  GPIOB
	#define SHARED_EN_PIN   GPIO_PIN_3

	/* Motor Instance Descriptor */
	typedef struct {
			GPIO_TypeDef* port;
			uint16_t pin_pul;
			uint16_t pin_dir;
			volatile bool is_busy;
	} MotorInst_t;

	/* Hardware Mapping Table */
	static MotorInst_t motors[4] = {
			{GPIOB, GPIO_PIN_4, GPIO_PIN_5, false}, /* MOTOR 1 */
			{GPIOB, GPIO_PIN_6, GPIO_PIN_7, false}, /* MOTOR 2 */
			{GPIOD, GPIO_PIN_0, GPIO_PIN_1, false}, /* MOTOR 3 */
			{GPIOD, GPIO_PIN_2, GPIO_PIN_3, false}  /* MOTOR 4 */
	};

	/* 160MHz Delay Calibration: 1us � 32 loop iterations */
	#define DELAY_US_COEFF  32U

/* USER CODE END PTD */


void SystemClock_Config(void);
/* USER CODE BEGIN 0 */
/**
  ******************************************************************************
  * @file           : main.c
  * @brief          : HBT42C 4-Axis Closed-Loop Stepper Motor Control
  * @wiring_info    :
  *                   MOTOR1: PU -> PB4,  DR -> PB5
  *                   MOTOR2: PU -> PB6,  DR -> PB7
  *                   MOTOR3: PU -> PD0,  DR -> PD1
  *                   MOTOR4: PU -> PD2,  DR -> PD3
  *                   SHARED ENA -> PB3   (Controls all 4 motors simultaneously)
  *                   All PU-/DR-/EN- pins -> MCU GND (Common-Cathode wiring)
  *                   DIP Switch SW1~SW4: ON/ON/ON/ON (400 Pulse/Rev)
  ******************************************************************************
  */



/**
 * @brief  Microsecond delay (calibrated for 160MHz system clock)
 * @param  nus: Delay duration in microseconds
 */
__STATIC_INLINE void delay_us(uint32_t nus)
{
    __IO uint32_t cycles = nus * DELAY_US_COEFF;
    while(cycles--);
}

/**
 * @brief  Global enable control for all 4 motors (Active-High per manual)
 */
__STATIC_INLINE void motor_global_enable(bool en)
{
    HAL_GPIO_WritePin(SHARED_EN_PORT, SHARED_EN_PIN, 
                      en ? GPIO_PIN_SET : GPIO_PIN_RESET);
}

/**
 * @brief  Set rotation direction for a specific motor
 */
__STATIC_INLINE void set_motor_dir(MotorInst_t* m, bool cw)
{
    HAL_GPIO_WritePin(m->port, m->pin_dir, 
                      cw ? GPIO_PIN_SET : GPIO_PIN_RESET);
}

/**
 * @brief  Output a single pulse with timing-compliant width
 */
__STATIC_INLINE void pulse_out(MotorInst_t* m, uint32_t half_us)
{
    /* Enforce t3/t4 >= 1.5us requirement from HBT42C manual */
    if(half_us < 2U) half_us = 2U;
    
    HAL_GPIO_WritePin(m->port, m->pin_pul, GPIO_PIN_SET);
    delay_us(half_us);
    HAL_GPIO_WritePin(m->port, m->pin_pul, GPIO_PIN_RESET);
    delay_us(half_us);
}

/**
 * @brief  Run specified motor for exactly 1 revolution (400 pulses)
 * @param  id: Motor index (0~3)
 * @param  cw: Direction (true=CW, false=CCW)
 * @note   Fixed parameters: 400 steps/rev, 60 RPM target, trapezoidal profile
 */
void motor_run(uint8_t id, bool cw)
{
    if(id >= 4U) return;
    MotorInst_t* m = &motors[id];
    m->is_busy = true;

    /* Fixed operational parameters */
    const uint32_t total_steps  = 400U;      /* 1 Revolution */
    const uint32_t start_freq   = 500U;      /* Safe startup frequency */
    const uint32_t target_freq  = 4000U;     /* 60 RPM @ 400 steps/rev */
    const uint32_t accel_steps  = 150U;      /* Accelerate first 150 steps */
    const uint32_t dec_start    = 250U;      /* Decelerate last 150 steps */
    
    /* Step 1: Enable drivers (t1: ENA high >=5us before DIR change) */
    motor_global_enable(true);
    delay_us(10U);

    /* Step 2: Set direction (t2: DIR stable >=1us before PUL) */
    set_motor_dir(m, cw);
    delay_us(5U);

    /* Step 3: Pulse generation with trapezoidal speed profile */
    uint32_t current_freq = start_freq;
    for(uint32_t step = 0; step < total_steps; step++)
    {
        /* Calculate half-period in microseconds */
        uint32_t half_period = 500000U / current_freq;
        pulse_out(m, half_period);

        /* Acceleration phase */
        if(step < accel_steps && current_freq < target_freq)
        {
            current_freq += (target_freq - start_freq) / accel_steps;
            if(current_freq > target_freq) current_freq = target_freq;
        }
        /* Deceleration phase */
        else if(step >= dec_start && current_freq > start_freq)
        {
            current_freq -= (target_freq - start_freq) / (total_steps - dec_start);
            if(current_freq < start_freq) current_freq = start_freq;
        }
    }

    m->is_busy = false;
}





/* USER CODE END 0 */

/**
  * @brief  The application entry point.
  * @retval int
  */
int main(void)
{

  /* MCU Configuration--------------------------------------------------------*/

  /* Reset of all peripherals, Initializes the Flash interface and the Systick. */
  HAL_Init();

  /* Configure the system clock */
  SystemClock_Config();

  /* Initialize all configured peripherals */
  MX_GPIO_Init();
  MX_USART1_UART_Init();
  MX_USART3_UART_Init();
  /* USER CODE BEGIN 2 */
	motor_global_enable(true);
  /* USER CODE END 2 */

  /* Infinite loop */
  /* USER CODE BEGIN WHILE */
  while (1)
  {
    /* USER CODE END WHILE */

    /* USER CODE BEGIN 3 */
		motor_run(0, true);  HAL_Delay(500);
    motor_run(1, false); HAL_Delay(500);
    motor_run(2, true);  HAL_Delay(500);
    motor_run(3, false); HAL_Delay(500);
  /* USER CODE END 3 */
}

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


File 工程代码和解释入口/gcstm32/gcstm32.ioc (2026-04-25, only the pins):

Mcu.UserName=STM32F407ZGTx
PA0-WKUP.Signal=S_TIM5_CH1
PA1.Signal=UART4_RX
PA10.Signal=USART1_RX
PA11.Signal=CAN1_RX
PA12.Signal=CAN1_TX
PA13.Signal=SYS_JTMS-SWDIO
PA14.Signal=SYS_JTCK-SWCLK
PA2.Signal=USART2_TX
PA3.Signal=USART2_RX
PA5.Signal=SPI1_SCK
PA6.Signal=SPI1_MISO
PA7.Signal=SPI1_MOSI
PA9.Signal=USART1_TX
PB10.Signal=USART3_TX
PB11.Signal=USART3_RX
PB3.Signal=GPIO_Output
PB4.Signal=GPIO_Output
PB5.Signal=GPIO_Output
PB6.Signal=GPIO_Output
PB7.Signal=GPIO_Output
PB8.Signal=I2C1_SCL
PB9.Signal=I2C1_SDA
PC10.Signal=UART4_TX
PD0.Signal=GPIO_Output
PD1.Signal=GPIO_Output
PD12.Signal=S_TIM4_CH1
PD2.Signal=GPIO_Output
PD3.Signal=GPIO_Output
PE9.Signal=S_TIM1_CH1
PH0-OSC_IN.Signal=RCC_OSC_IN
PH1-OSC_OUT.Signal=RCC_OSC_OUT

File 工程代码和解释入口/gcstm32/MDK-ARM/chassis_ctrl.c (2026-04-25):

#include "chassis_ctrl.h"
#include <stdlib.h>
#include <math.h>

// ?????? (M1??, M2??, M3??, M4??)
const MotorPin_t chassis_motors[4] = {
    {GPIOB, GPIO_PIN_4, GPIO_PIN_5},   // M1
    {GPIOB, GPIO_PIN_6, GPIO_PIN_7},   // M2
    {GPIOD, GPIO_PIN_0, GPIO_PIN_1},   // M3
    {GPIOD, GPIO_PIN_2, GPIO_PIN_3}    // M4
};

// ??????
static ChassisCtrl_t ctrl = {0};

// ?????? (??DWT)
__STATIC_INLINE void delay_us_precise(uint32_t us) {
    if (!(CoreDebug->DEMCR & CoreDebug_DEMCR_TRCENA_Msk)) {
        CoreDebug->DEMCR |= CoreDebug_DEMCR_TRCENA_Msk;
        DWT->CYCCNT = 0;
        DWT->CTRL |= DWT_CTRL_CYCCNTENA_Msk;
    }
    uint32_t start = DWT->CYCCNT;
    uint32_t ticks = us * (SystemCoreClock / 1000000U);
    while ((DWT->CYCCNT - start) < ticks);
}

// ============================================================
// ????? (???????????)
// ???: +X??, +Y??, +W???(???)
// ????: ????(M2,M3)???????,??????
// ============================================================
static void compute_wheel_speeds(float vx, float vy, float w, float speeds[4]) {
    speeds[0] =  vx + vy + w * ROBOT_RADIUS;  // M1 ?? (??,??)
    speeds[1] = -vx + vy + w * ROBOT_RADIUS;  // M2 ?? (??,????)
    speeds[2] = -vx - vy + w * ROBOT_RADIUS;  // M3 ?? (??,????)
    speeds[3] =  vx - vy + w * ROBOT_RADIUS;  // M4 ?? (??,??)
}

void chassis_init(void) {
    for (int i = 0; i < 4; i++) {
        // ???????????
        chassis_motors[i].port->BSRR = (uint32_t)chassis_motors[i].pin_pul << 16U;
        chassis_motors[i].port->BSRR = (uint32_t)chassis_motors[i].pin_dir << 16U;
    }
    // ?????? (????????)
    #ifdef CHASSIS_EN_PORT
    HAL_GPIO_WritePin(CHASSIS_EN_PORT, CHASSIS_EN_PIN, GPIO_PIN_SET);
    #endif
    delay_us_precise(100);
}

// ============================
// ???? (???)
// ============================
void chassis_move(float vx, float vy, float speed) {
    if (ctrl.is_running) return;

    float wheel_speed[4];
    compute_wheel_speeds(vx, vy, 0.0f, wheel_speed);

    ctrl.max_steps = 0;
    for (int i = 0; i < 4; i++) {
        ctrl.steps[i] = (int32_t)(wheel_speed[i] * PULSES_PER_METER * PULSE_CALIBRATION_FACTOR);
        ctrl.dir[i] = (ctrl.steps[i] >= 0) ? GPIO_PIN_SET : GPIO_PIN_RESET;
        ctrl.abs_steps[i] = (uint32_t)abs(ctrl.steps[i]);
        if (ctrl.abs_steps[i] > ctrl.max_steps)
            ctrl.max_steps = ctrl.abs_steps[i];
    }
    if (ctrl.max_steps == 0) return;

    ctrl.target_freq = (uint32_t)(speed * PULSES_PER_METER * PULSE_CALIBRATION_FACTOR);
    if (ctrl.target_freq > MAX_FREQ_HZ) ctrl.target_freq = MAX_FREQ_HZ;
    if (ctrl.target_freq < START_FREQ_HZ) ctrl.target_freq = START_FREQ_HZ;

    // ??????
    for (int i = 0; i < 4; i++) {
        if (ctrl.dir[i] == GPIO_PIN_SET)
            chassis_motors[i].port->BSRR = chassis_motors[i].pin_dir;
        else
            chassis_motors[i].port->BSRR = (uint32_t)chassis_motors[i].pin_dir << 16U;
    }
    delay_us_precise(10);

    // ??????
    ctrl.acc_steps = (uint32_t)(ctrl.max_steps * ACC_RATIO);
    if (ctrl.acc_steps == 0) ctrl.acc_steps = 1;
    if (ctrl.acc_steps > ctrl.max_steps / 2) ctrl.acc_steps = ctrl.max_steps / 2;
    ctrl.dec_start = ctrl.max_steps - ctrl.acc_steps;
    
    ctrl.freq_now = (float)START_FREQ_HZ;
    ctrl.current_step = 0;
    ctrl.is_running = true;
    for (int i = 0; i < 4; i++) ctrl.bresenham_err[i] = 0;

    // ??????
    while (ctrl.current_step < ctrl.max_steps) {
        // S?/?????
        if (ctrl.current_step < ctrl.acc_steps && ctrl.freq_now < ctrl.target_freq) {
            ctrl.freq_now += (float)(ctrl.target_freq - START_FREQ_HZ) / (float)ctrl.acc_steps;
        } else if (ctrl.current_step >= ctrl.dec_start && ctrl.freq_now > START_FREQ_HZ) {
            ctrl.freq_now -= (float)(ctrl.target_freq - START_FREQ_HZ) / (float)ctrl.acc_steps;
        }
        if (ctrl.freq_now > ctrl.target_freq) ctrl.freq_now = (float)ctrl.target_freq;
        if (ctrl.freq_now < START_FREQ_HZ) ctrl.freq_now = (float)START_FREQ_HZ;

        // Bresenham ????
        uint32_t pulse_mask = 0;
        for (int i = 0; i < 4; i++) {
            ctrl.bresenham_err[i] += ctrl.abs_steps[i];
            if (ctrl.bresenham_err[i] >= ctrl.max_steps) {
                ctrl.bresenham_err[i] -= ctrl.max_steps;
                pulse_mask |= (1U << i);
            }
        }

        // ????
        if (pulse_mask & 0x01) GPIOB->BSRR = GPIO_PIN_4;
        if (pulse_mask & 0x02) GPIOB->BSRR = GPIO_PIN_6;
        if (pulse_mask & 0x04) GPIOD->BSRR = GPIO_PIN_0;
        if (pulse_mask & 0x08) GPIOD->BSRR = GPIO_PIN_2;
        delay_us_precise(2); // ???????
        
        if (pulse_mask & 0x01) GPIOB->BSRR = GPIO_PIN_4 << 16U;
        if (pulse_mask & 0x02) GPIOB->BSRR = GPIO_PIN_6 << 16U;
        if (pulse_mask & 0x04) GPIOD->BSRR = GPIO_PIN_0 << 16U;
        if (pulse_mask & 0x08) GPIOD->BSRR = GPIO_PIN_2 << 16U;

        uint32_t period_us = (uint32_t)(1000000.0f / ctrl.freq_now);
        if (period_us > 2) delay_us_precise(period_us - 2);
        ctrl.current_step++;
    }
    ctrl.is_running = false;
}
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

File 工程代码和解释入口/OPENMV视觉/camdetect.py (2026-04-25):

import sensor, image, time
from pyb import UART
from pyb import Pin

sensor.reset()
sensor.set_pixformat(sensor.RGB565)
sensor.set_framesize(sensor.QVGA)
sensor.set_windowing((0, 0, 260, 240))
sensor.set_auto_gain(False)
sensor.set_auto_whitebal(False)
sensor.skip_frames(time=2000)

uart = UART(3, 115200)
p0 = Pin('P0', Pin.OUT_PP, Pin.PULL_NONE)

print("Ready. Send 1/2/3 to set order")

W = 260
H = 240
RW = 30
RH = 30
RX = 115
RY = 105
ROI = (RX, RY, RW, RH)

MIN_VALID_PIXELS = 80

CODE_MAP = {'1': 'R', '2': 'G', '3': 'B'}
COLOR_CN   = {'R': 'R', 'G': 'G', 'B': 'B'}

LAB_THRESHOLDS = {
    'R': [(35, 85, 30, 85, 10, 70)],
    'G': [(40, 85, -70, -20, 20, 60)],
    'B': [(35, 80, -15, 25, -65, -20)]
}

STATE_WAIT_ORDER = 0
STATE_TRACKING = 2
current_state = STATE_WAIT_ORDER

ok_count = 0
target_color = None
start_time = 0
MAX_TRACK_TIME = 3000
ALIGN_OK_COUNT = 5
ALIGN_PIXEL = 15

while True:
    if current_state == STATE_WAIT_ORDER:
        if uart.any():
            data = uart.read()
            if data:
                try:
                    recv_str = data.decode()
                    for c in recv_str:
                        if c in CODE_MAP:
                            target_color = CODE_MAP[c]
                            print("Target:" + target_color)
                            ok_count = 0
                            current_state = STATE_TRACKING
                            start_time = time.ticks_ms()
                            break
                except:
                    pass
        time.sleep_ms(20)
        continue

    elif current_state == STATE_TRACKING:
        current_ms = time.ticks_ms()
        use_time = current_ms - start_time
        if use_time > MAX_TRACK_TIME:
            current_state = STATE_WAIT_ORDER
            target_color = None
            ok_count = 0
            p0.low()
            uart.write("NONE\n")
            continue

        p0.high()
        img = sensor.snapshot()
        img.binary(LAB_THRESHOLDS[target_color])

        blobs = img.find_blobs([(0, 255)], pixels_threshold=80, area_threshold=80, merge=True)

        if blobs:
            blob = max(blobs, key=lambda b: b.pixels())

            if blob.pixels() >= MIN_VALID_PIXELS:
                # ======================================================
                # 【改动 1】把最大色块范围存到数组(元组)里
                # ======================================================
                blob_roi = (blob.x(), blob.y(), blob.w(), blob.h())

                # ======================================================
                # 【改动 2】霍夫圆只在这个 blob_roi 里检测
                # ======================================================
                circles = img.find_circles(
                    roi=blob_roi,          # <--- 这里用了色块范围
                    threshold=1800,
                    min_radius=15,
                    max_radius=60,
                    circles_max=1
                )

                cx, cy = 999, 999
                valid = False

                if circles:
                    c = circles[0]
                    cx = c.x()
                    cy = c.y()
                    valid = True
                    img.draw_circle(cx, cy, c.r(), color=(255,0,0))
                    img.draw_cross(cx, cy, color=(255,0,0))

                img.draw_rectangle(ROI, color=(255,0,0), thickness=2)

                if valid:
                    dx = cx - 130
                    dy = cy - 120

                    if abs(dx) <= ALIGN_PIXEL and abs(dy) <= ALIGN_PIXEL:
                        uart.write("LR:=,UD:=\n")
                        ok_count += 1
                    else:
                        lr = '+' if dx > 0 else '-'
                        ud = '+' if dy < 0 else '-'
                        uart.write("LR:%s,UD:%s\n" % (lr, ud))
                        ok_count = 0

                    if ok_count >= ALIGN_OK_COUNT:
                        uart.write("DONE\n")
                        p0.low()
                        current_state = STATE_WAIT_ORDER
                        target_color = None
                        ok_count = 0

                    time.sleep_ms(100)
                    continue

        uart.write("NONE\n")
        ok_count = 0
        time.sleep_ms(100)

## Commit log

2026-03-30 首次更新，然后详情请看readme
    [10mm铜柱.SLDPRT, 10mm铜柱.step, 16mm铜柱（m2）.SLDPRT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]
2026-04-16 完成了步进电机的初步的各层次的函数封装，现在可以较为自由的控制各路电机；视觉部分用了HSV可以初步实现识别功能，接下来的主要问题就是无目标的处理，是个问题，然后就是具体的调车了，但是这个的话就是感觉还是需要一个补光灯，考虑外接一个灯板
2026-04-17 完善了视觉相关的代码，基本保障机械臂末端的视觉处理的稳定性和消息的确定性，最后完成了大部分的时序和判断
2026-04-19 完成了这个地盘运动学公式的控制，然后视觉部分完善了代码和这个为了互动的专门的代码，然后初步调参完成了这个地盘的一个距离的一个补偿系数的一个调试具体的机器人的接线也是比较接近完成只有接下来的一些云台控制的舵机或者这个夹爪的这个控制舵机的线没有做完，下一步就是这个具体的跑流程，和这个抓取放置的具体的流程化操作了，但是具体的机械臂的升降的自由度的电机还没到，而且那个的控制流程和别的电机还不太一样，今天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
2026-04-25 视觉的配合逻辑因为底盘运动学的文件的参数和函数结构变更重新调整完毕，现在是每次持续3s，每次收到的信号会移动2cm左右然后延迟50ms，所以一共执行5~6次，基本可以完成普通的对准任务，下一步是这个具体的上车调试。总体进度相差还是甚多。

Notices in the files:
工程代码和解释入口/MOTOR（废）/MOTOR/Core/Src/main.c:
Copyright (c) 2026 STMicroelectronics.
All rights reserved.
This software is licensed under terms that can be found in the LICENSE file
